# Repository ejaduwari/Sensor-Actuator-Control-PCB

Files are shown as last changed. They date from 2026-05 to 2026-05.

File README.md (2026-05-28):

# Sensor-Actuator-Control-PCB
STM32F103C8 carrier board controlling 6 stepper motors, servos, limit switches, and IO expanders with UART, SPI, and I2C interfaces. Includes full pin mapping, dual-regulator power design, and detailed failure analysis with debugging insights and hardware lessons learned.



# 📘 STM32F103C8 Stepper Motor Controller  
### Carrier Board + Small Pill Architecture & Debug Report

---

## 📑 Table of Contents
- [Overview](#overview)
- [Hardware Architecture](#hardware-architecture)
- [Pin Mapping (STM32 ↔ Carrier Board)](#pin-mapping-stm32--carrier-board)
- [Peripheral Interfaces](#peripheral-interfaces)
- [Clock & Crystal](#clock--crystal)
- [Power System Design](#power-system-design)
- [IO Expanders](#io-expanders)
- [Failure Report & Debugging](#failure-report--debugging)
- [Root Cause Analysis](#root-cause-analysis)
- [Current Status](#current-status)
- [Design Lessons & Prevention](#design-lessons--prevention)

---

## 🔍 Overview

This project is a **custom STM32F103C8-based PCB** designed to control:
- Multiple **A4988 stepper drivers**
- Several **servo outputs**
- External IO via expanders

The board uses a **Small Pill (STM32F103C8T6)** mounted on a **carrier board**, providing structured routing for motion control and expansion.

---

## 🧩 Hardware Architecture

- **MCU:** STM32F103C8T6 (Small Pill)
- **Motor Drivers:** A4988 (external)
- **IO Expansion:** PI4IOE5V6416
- **Power Inputs:**
  - USB (via L78L00 regulator)
  - External 5V (via AP2112K-3.3)
- **Control Signals:**
  - STEP / DIR for 6 axes
  - Servo PWM outputs
- **Debug Interface:**
  - SWD (SWCLK, SWDIO)

---

## 🔌 Pin Mapping (STM32 ↔ Carrier Board)

| STM32 Pin | Function |
|---|---|
| PA0 | 5_DIR |
| PA1 | 5_STP |
| PA2 | TX |
| PA3 | RX |
| PA4 | 1_DIR |
| PA5 | SCK |
| PA6 | MISO |
| PA7 | MOSI |
| PA8 | SERVO_1_3V3 |
| PA9 | SERVO_2_3V3 |
| PA10 | SERVO_3_3V3 |
| PA11 | USB- |
| PA12 | USB+ |
| PA15 | SERVO_4_3V3 |

| STM32 Pin | Function |
|---|---|
| PB0 | 4_STP |
| PB1 | 4_DIR |
| PB2 | BOOT |
| PB3 | 3_STP |
| PB4 | SERVO_6_3V3 |
| PB5 | SW9 |
| PB6 | SCL |
| PB7 | SDA |
| PB8 | 6_DIR |
| PB9 | SW10 |
| PB10 | 3_DIR |
| PB11 | 6_STP |
| PB12 | LED |
| PB13 | GPIO |
| PB14 | GPIO |
| PB15 | GPIO |

| STM32 Pin | Function |
|---|---|
| PC13 | 2_DIR |
| PC14 | 2_STP |
| PC15 | 1_STP |

| Debug Pins | Function |
|---|---|
| PA13 | SWDIO |
| PA14 | SWCLK |
| NRST | Reset |

---

## 🔗 Peripheral Interfaces

### UART
- TX: PA2  
- RX: PA3  

### SPI
- SCK: PA5  
- MISO: PA6  
- MOSI: PA7  

### I2C
- SCL: PB6  
- SDA: PB7  

---

## ⏱ Clock & Crystal

- **Component:** 25 MHz SMD Crystal  
- **Capacitance:** 20pF  
- **Package:** 3.2mm × 2.5mm  

- **DigiKey Part #:** 3155-25M20P2/XT324-10/10CT-ND  
- **Manufacturer #:** 25M20P2/XT324-10/10  

---

## ⚡ Power System Design

### Regulators

**1. L78L00**
- Input: USB (~5V)
- Output: 3.3V (intended)
- Status: ❌ Damaged / unstable

**2. AP2112K-3.3**
- Input: External 5V
- Output: 3.3V
- Status: ✅ Functional

---

### Observed Behavior

- With motors connected:
  - 3.3V rail dropped to ~3.0V
- With L78L00 removed:
  - Stable 3.29V from AP2112K
- Backfeeding observed across regulators

---

## 🔌 IO Expanders

- **Model:** PI4IOE5V6416  
- Used for:
  - Microstepping control
  - Enable signals

⚠️ These lines interface with high-current drivers → risk area

---

## 🧪 Failure Report & Debugging

### Initial Symptoms

- PB12 LED stopped working
- MCU still flashable (initially)
- Reset did not recover functionality

---

### Voltage Measurements

| Condition | Observation |
|---|---|
| Motors connected | 3.3V ~3.0V |
| PB12 | ~0.12V |
| After disconnecting 12V | PB12 still ~0.12V |
| Reset held | 3.3V rises slightly |

---

### GPIO Testing

- PB12–PB15 stuck at ~0.12V
- PB15 toggle test failed
- Same issue after MCU replacement

---

### Regulator Testing

- L78L00:
  - Input ~4.8V
  - Output unstable / low
- AP2112K:
  - Output stable at ~3.29V

---

### Fuse

- 0685H9100-01 → OK (~0Ω)

---

### After L78L00 Removal

- System powered via AP2112K
- 3.3V stable
- ❌ Flashing failed:
  - Error in final launch sequence
  - Failed to start GDB server

---

## 🔎 Root Cause Analysis

### 1. GPIO Damage
- PB12–PB15 permanently stuck low
- Cause: **Backfeed / overvoltage from stepper drivers**
- Likely triggered by:
- Swapping motor wires while powered

---

### 2. Power Rail Instability
- L78L00 regulator damaged
- Caused rail drops under load

---

### 3. Regulator Conflict
- Backfeeding between regulators
- L78L00 became ineffective

---

### 4. Flashing Failure
- Likely due to:
- Unstable VDD reference
- Improper SWD voltage levels

---

## 📉 Current Status

- ❌ Original MCU damaged (GPIO bank failure)
- ⚠️ Replacement MCU still showing abnormal GPIO behavior
- ✅ AP2112K regulator working
- ❌ Board cannot be flashed
- ❌ System non-functional

---

## 🛠 Design Lessons & Prevention

### Critical Rules

- ❌ Never swap stepper wires under power
- ❌ Avoid direct MCU exposure to driver signals

---

### Recommended Fixes

- Add **series resistors** on control lines
- Use **optocouplers or buffers**
- Isolate **high-current paths**
- Ensure **single clean 3.3V source**
- Avoid regulator backfeeding

---

### Debug Best Practices

- Verify rails before applying load
- Test MCU pins before connecting drivers
- Use current limiting during bring-up

---

## 🚧 Final Note

This failure highlights a critical embedded design principle:

> **Power integrity and signal protection are just as important as logic design.**

Future revisions should prioritize:
- Electrical isolation
- Robust power architecture
- Safer bring-up procedures

---

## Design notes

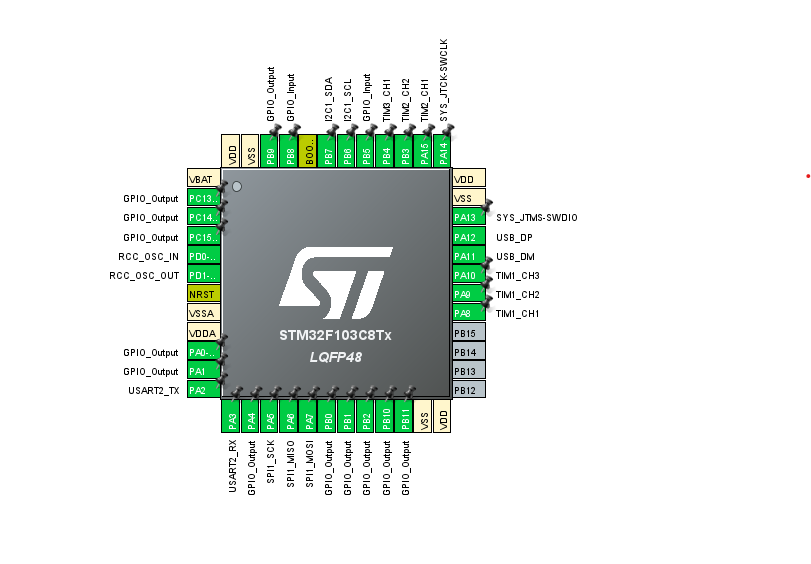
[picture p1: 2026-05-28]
pin map.png

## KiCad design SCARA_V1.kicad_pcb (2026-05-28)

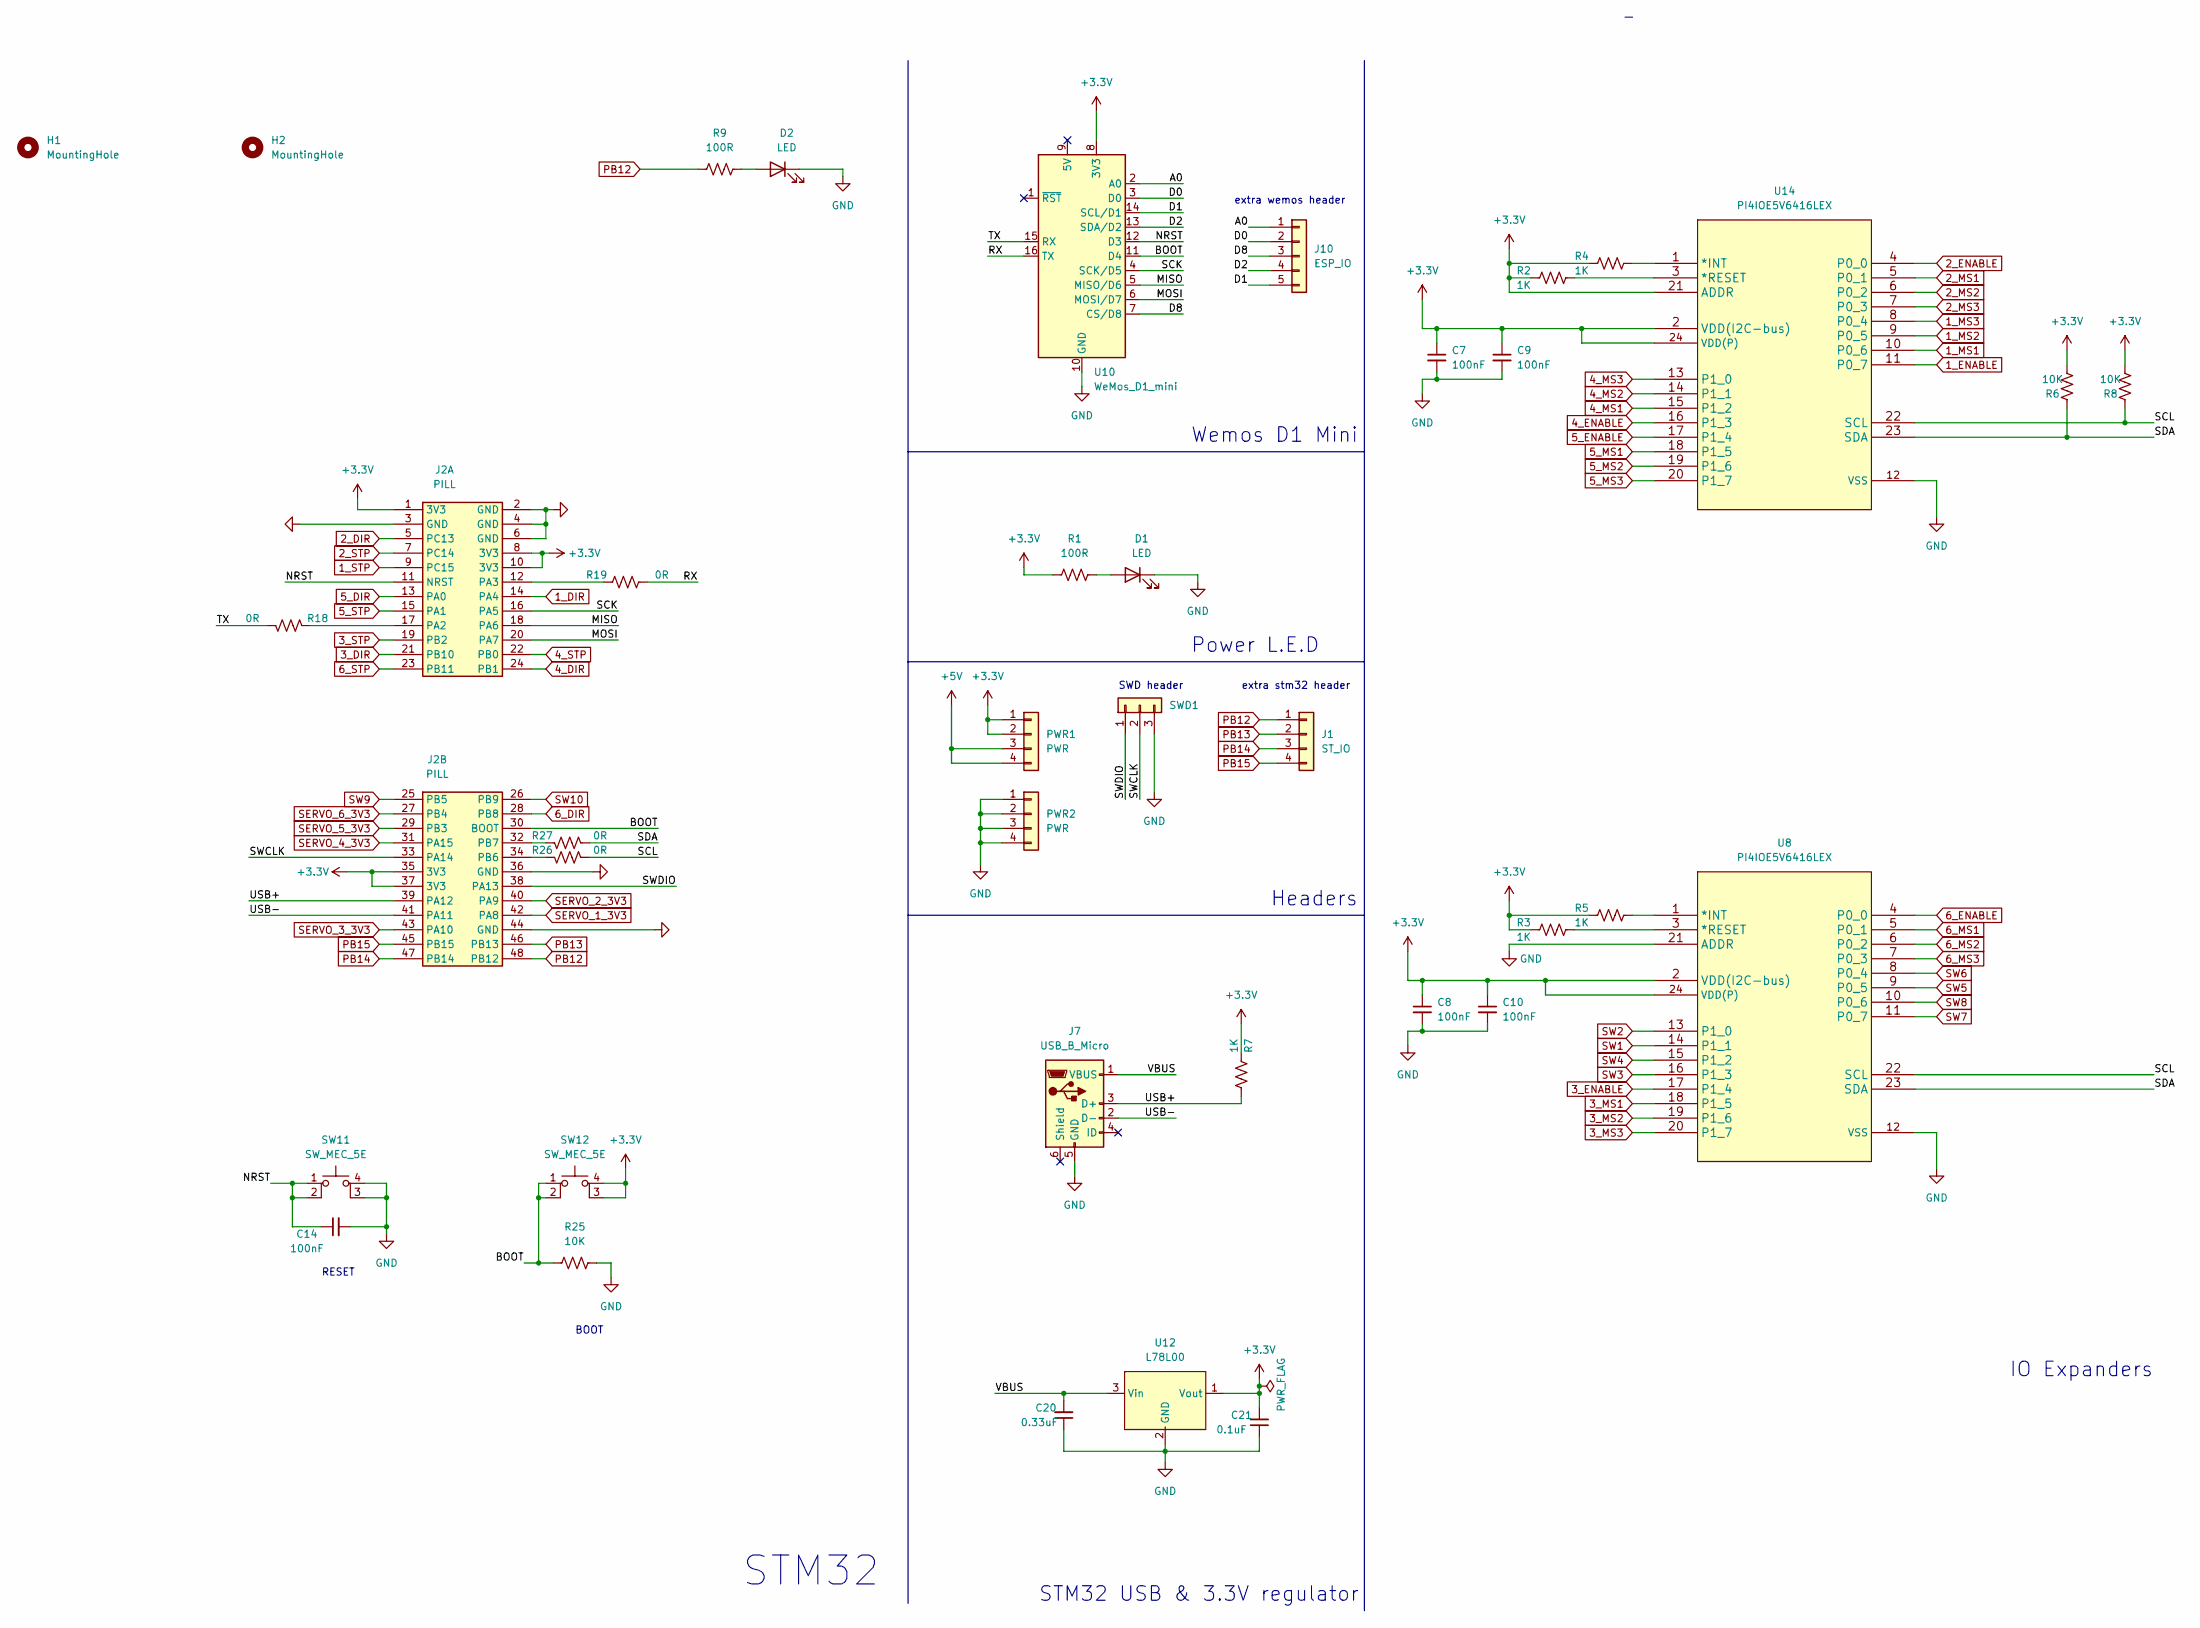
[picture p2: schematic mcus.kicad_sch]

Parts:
C7, C8, C9, C10: 100nF; C_0402_1005Metric
C14: 100nF; C_0805_2012Metric
C20: 0.33uF; C_0805_2012Metric_Pad1.18x1.45mm_HandSolder
C21: 0.1uF; C_0805_2012Metric_Pad1.18x1.45mm_HandSolder
D1, D2: LED; LED_0805_2012Metric
H1, H2: MountingHole; MountingHole_3.5mm
J1: ST_IO; PinHeader_1x04_P2.54mm_Vertical
J2: PILL
J7: USB_B_Micro; USB_Micro-B_Molex-105017-0001
J10: ESP_IO; PinHeader_1x05_P2.54mm_Vertical
PWR1, PWR2: PWR; PinHeader_1x04_P2.54mm_Vertical
R1, R9: 100R; R_0805_2012Metric
R2, R3, R4, R5, R7: 1K; R_0805_2012Metric
R6, R8, R25: 10K; R_0805_2012Metric
R18, R19, R26, R27: 0R; R_0805_2012Metric
SW11, SW12: SW_MEC_5E; PTS830GM140SMTRLFS
SWD1: Conn_01x03; PinHeader_1x03_P2.54mm_Vertical
U8, U14: PI4IOE5V6416LEX; TSSOP-24_4.4x7.8mm_P0.65mm
U10: WeMos_D1_mini; WEMOS_D1_mini_light
U12: L78L00; SOT-89-3

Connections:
1_DIR: J2.14 (PA4); also elsewhere on the board
1_ENABLE: U14.11 (P0_7); also elsewhere on the board
1_MS1: U14.10 (P0_6); also elsewhere on the board
1_MS2: U14.9 (P0_5); also elsewhere on the board
1_MS3: U14.8 (P0_4); also elsewhere on the board
1_STP: J2.9 (PC15); also elsewhere on the board
2_DIR: J2.5 (PC13); also elsewhere on the board
2_ENABLE: U14.4 (P0_0); also elsewhere on the board
2_MS1: U14.5 (P0_1); also elsewhere on the board
2_MS2: U14.6 (P0_2); also elsewhere on the board
2_MS3: U14.7 (P0_3); also elsewhere on the board
2_STP: J2.7 (PC14); also elsewhere on the board
3_DIR: J2.21 (PB10); also elsewhere on the board
3_ENABLE: U8.17 (P1_4); also elsewhere on the board
3_MS1: U8.18 (P1_5); also elsewhere on the board
3_MS2: U8.19 (P1_6); also elsewhere on the board
3_MS3: U8.20 (P1_7); also elsewhere on the board
3_STP: J2.19 (PB2); also elsewhere on the board
4_DIR: J2.24 (PB1); also elsewhere on the board
4_ENABLE: U14.16 (P1_3); also elsewhere on the board
4_MS1: U14.15 (P1_2); also elsewhere on the board
4_MS2: U14.14 (P1_1); also elsewhere on the board
4_MS3: U14.13 (P1_0); also elsewhere on the board
4_STP: J2.22 (PB0); also elsewhere on the board
5_DIR: J2.13 (PA0); also elsewhere on the board
5_ENABLE: U14.17 (P1_4); also elsewhere on the board
5_MS1: U14.18 (P1_5); also elsewhere on the board
5_MS2: U14.19 (P1_6); also elsewhere on the board
5_MS3: U14.20 (P1_7); also elsewhere on the board
5_STP: J2.15 (PA1); also elsewhere on the board
6_DIR: J2.28 (PB8); also elsewhere on the board
6_ENABLE: U8.4 (P0_0); also elsewhere on the board
6_MS1: U8.5 (P0_1); also elsewhere on the board
6_MS2: U8.6 (P0_2); also elsewhere on the board
6_MS3: U8.7 (P0_3); also elsewhere on the board
6_STP: J2.23 (PB11); also elsewhere on the board
+3.3V: C7.1, C8.1, C9.1, C10.1, C21.2, J2.1 (3V3), J2.8 (3V3), J2.10 (3V3), J2.35 (3V3), J2.37 (3V3), PWR1.1, PWR1.2, R1.1, R2.2, R3.2, R4.2, R5.2, R6.1, R7.2, R8.1, SW12.3 (K), SW12.4 (A), U8.2 (VDD(I2C-bus)), U8.24 (VDD(P)), U10.8 (3V3), U12.1 (Vout), U14.2 (VDD(I2C-bus)), U14.21 (ADDR), U14.24 (VDD(P)); also elsewhere on the board
+5V: PWR1.3, PWR1.4; also elsewhere on the board
/MCUs/A0: J10.1, U10.2 (A0)
/MCUs/BOOT: J2.30 (BOOT), R25.1, SW12.1, SW12.2, U10.11 (D4)
/MCUs/D0: J10.2, U10.3 (D0)
/MCUs/D1: J10.5, U10.14 (SCL/D1)
/MCUs/D2: J10.4, U10.13 (SDA/D2)
/MCUs/D8: J10.3, U10.7 (CS/D8)
/MCUs/MISO: J2.18 (PA6), U10.5 (MISO/D6)
/MCUs/MOSI: J2.20 (PA7), U10.6 (MOSI/D7)
/MCUs/NRST: C14.1, J2.11 (NRST), SW11.1, SW11.2, U10.12 (D3)
/MCUs/RX: R19.2, U10.16 (TX)
/MCUs/SCK: J2.16 (PA5), U10.4 (SCK/D5)
/MCUs/SCL: R8.2, R26.1, U8.22 (SCL), U14.22 (SCL)
/MCUs/SDA: R6.2, R27.1, U8.23 (SDA), U14.23 (SDA)
/MCUs/SWCLK: J2.33 (PA14), SWD1.2
/MCUs/SWDIO: J2.38 (PA13), SWD1.1
/MCUs/TX: R18.2, U10.15 (RX)
/MCUs/USB+: J2.39 (PA12), J7.3 (D+), R7.1
/MCUs/USB-: J2.41 (PA11), J7.2 (D-)
/MCUs/VBUS: C20.2, J7.1 (VBUS), U12.3 (Vin)
GND: C7.2, C8.2, C9.2, C10.2, C14.2, C20.1, C21.1, D1.1 (K), D2.1 (K), J2.2 (GND), J2.3 (GND), J2.4 (GND), J2.6 (GND), J2.36 (GND), J2.44 (GND), J7.5 (GND), PWR2.1, PWR2.2, PWR2.3, PWR2.4, R25.2, SW11.3 (K), SW11.4 (A), SWD1.3, U8.12 (VSS), U8.21 (ADDR), U10.10 (GND), U12.2 (GND), U14.12 (VSS); also elsewhere on the board
unnamed: D1.2 (A), R1.2
unnamed: D2.2 (A), R9.2
unnamed: J2.12 (PA3), R19.1
unnamed: J2.17 (PA2), R18.1
unnamed: J2.32 (PB7), R27.2
unnamed: J2.34 (PB6), R26.2
unnamed: R2.1, U14.3 (*RESET)
unnamed: R3.1, U8.3 (*RESET)
unnamed: R4.1, U14.1 (*INT)
unnamed: R5.1, U8.1 (*INT)
PB12: J1.1, J2.48 (PB12), R9.1
PB13: J1.2, J2.46 (PB13)
PB14: J1.3, J2.47 (PB14)
PB15: J1.4, J2.45 (PB15)
SERVO_1_3V3: J2.42 (PA8); also elsewhere on the board
SERVO_2_3V3: J2.40 (PA9); also elsewhere on the board
SERVO_3_3V3: J2.43 (PA10); also elsewhere on the board
SERVO_4_3V3: J2.31 (PA15); also elsewhere on the board
SERVO_5_3V3: J2.29 (PB3); also elsewhere on the board
SERVO_6_3V3: J2.27 (PB4); also elsewhere on the board
SW1: U8.14 (P1_1); also elsewhere on the board
SW2: U8.13 (P1_0); also elsewhere on the board
SW3: U8.16 (P1_3); also elsewhere on the board
SW4: U8.15 (P1_2); also elsewhere on the board
SW5: U8.9 (P0_5); also elsewhere on the board
SW6: U8.8 (P0_4); also elsewhere on the board
SW7: U8.11 (P0_7); also elsewhere on the board
SW8: U8.10 (P0_6); also elsewhere on the board
SW9: J2.25 (PB5); also elsewhere on the board
SW10: J2.26 (PB9); also elsewhere on the board

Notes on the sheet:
extra stm32 header
STM32
extra wemos header
SWD header
IO Expanders
Wemos D1 Mini
BOOT
STM32 USB & 3.3V regulator
RESET
Power L.E.D
Headers

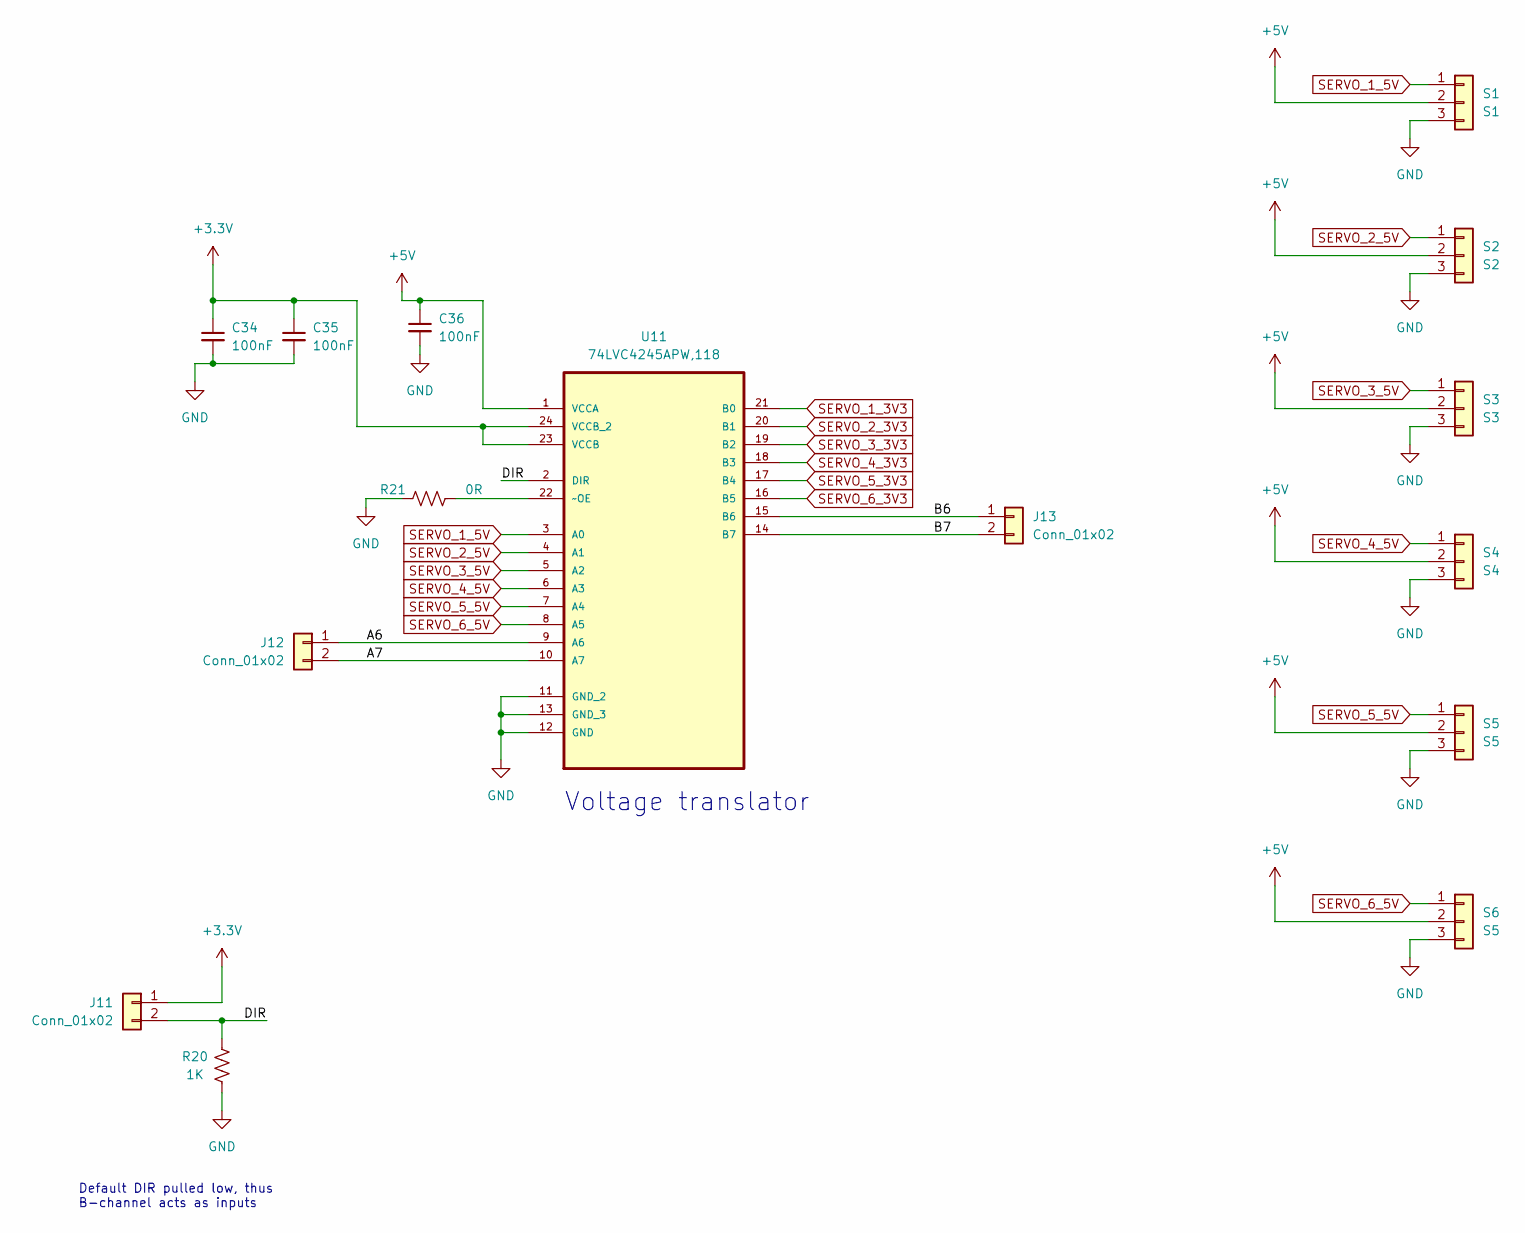
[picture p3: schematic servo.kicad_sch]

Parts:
C34, C35, C36: 100nF; C_0805_2012Metric
J11, J12, J13: Conn_01x02; PinHeader_1x02_P2.54mm_Vertical
R20: 1K; R_0805_2012Metric
R21: 0R; R_0805_2012Metric
S1: S1; PinHeader_1x03_P2.54mm_Vertical
S2: S2; PinHeader_1x03_P2.54mm_Vertical
S3: S3; PinHeader_1x03_P2.54mm_Vertical
S4: S4; PinHeader_1x03_P2.54mm_Vertical
S5, S6: S5; PinHeader_1x03_P2.54mm_Vertical
U11: 74LVC4245APW,118; SOP65P640X110-24N; MPN 74LVC4245APW,118

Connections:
+3.3V: C34.1, C35.1, J11.1, U11.23 (VCCB), U11.24 (VCCB_2); also elsewhere on the board
+5V: C36.1, S1.2, S2.2, S3.2, S4.2, S5.2, S6.2, U11.1 (VCCA); also elsewhere on the board
/SERVOS/A6: J12.1, U11.9 (A6)
/SERVOS/A7: J12.2, U11.10 (A7)
/SERVOS/B6: J13.1, U11.15 (B6)
/SERVOS/B7: J13.2, U11.14 (B7)
/SERVOS/DIR: J11.2, R20.2, U11.2 (DIR)
GND: C34.2, C35.2, C36.2, R20.1, R21.1, S1.3, S2.3, S3.3, S4.3, S5.3, S6.3, U11.11 (GND_2), U11.12 (GND), U11.13 (GND_3); also elsewhere on the board
unnamed: R21.2, U11.22 (~OE)
SERVO_1_3V3: U11.21 (B0); also elsewhere on the board
SERVO_1_5V: S1.1, U11.3 (A0)
SERVO_2_3V3: U11.20 (B1); also elsewhere on the board
SERVO_2_5V: S2.1, U11.4 (A1)
SERVO_3_3V3: U11.19 (B2); also elsewhere on the board
SERVO_3_5V: S3.1, U11.5 (A2)
SERVO_4_3V3: U11.18 (B3); also elsewhere on the board
SERVO_4_5V: S4.1, U11.6 (A3)
SERVO_5_3V3: U11.17 (B4); also elsewhere on the board
SERVO_5_5V: S5.1, U11.7 (A4)
SERVO_6_3V3: U11.16 (B5); also elsewhere on the board
SERVO_6_5V: S6.1, U11.8 (A5)

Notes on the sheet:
Default DIR pulled low, thus B-channel acts as inputs
Voltage translator

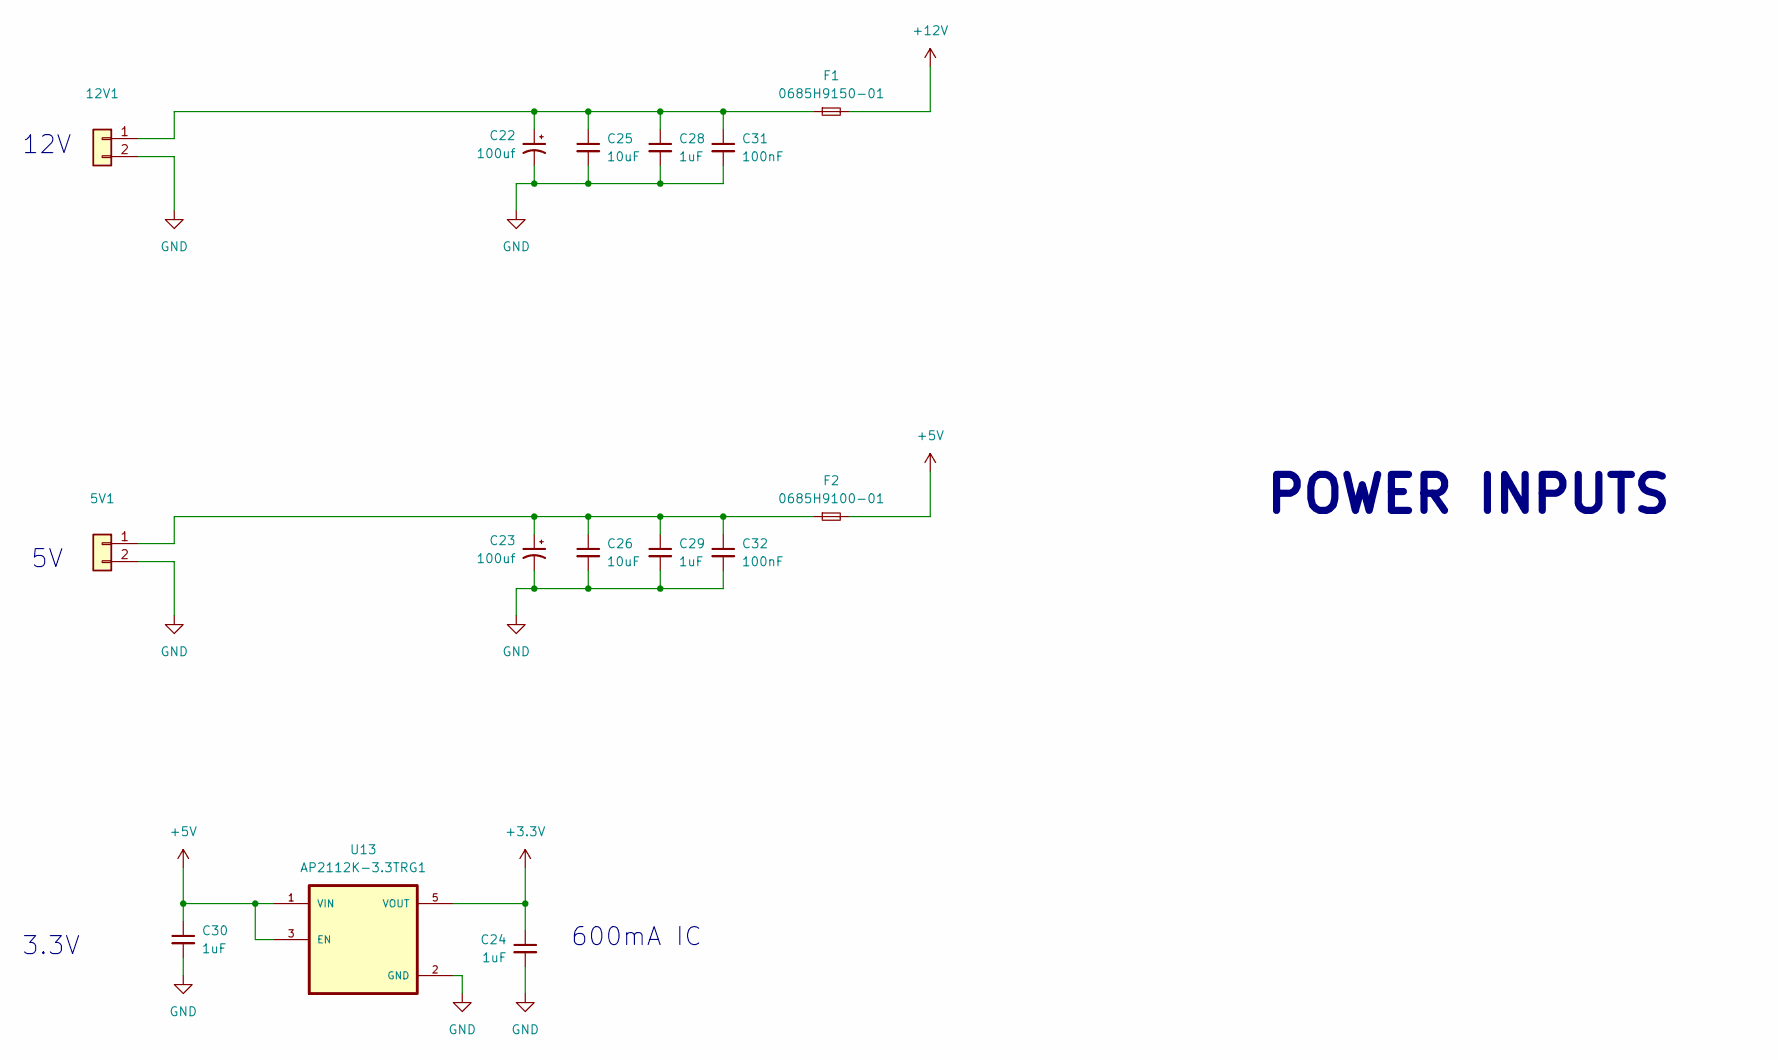
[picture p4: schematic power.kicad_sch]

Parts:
5V1, 12V1: Conn_01x02; PinHeader_1x02_P2.54mm_Vertical
C22, C23: 100uf; CP_Radial_D6.3mm_P2.50mm
C24, C28, C29, C30: 1uF; C_0805_2012Metric
C25, C26: 10uF; C_0805_2012Metric
C31, C32: 100nF; C_0805_2012Metric
F1: 0685H9150-01; 3.2x1.58
F2: 0685H9100-01; 3.2x1.58
U13: AP2112K-3.3TRG1; SOT95P285X140-5N; PARTREV 2-2

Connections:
+3.3V: C24.1, U13.5 (VOUT); also elsewhere on the board
+5V: C30.1, F2.2, U13.1 (VIN), U13.3 (EN); also elsewhere on the board
+12V: F1.2; also elsewhere on the board
GND: 5V1.2, 12V1.2, C22.2, C23.2, C24.2, C25.2, C26.2, C28.2, C29.2, C30.2, C31.2, C32.2, U13.2 (GND); also elsewhere on the board
unnamed: 5V1.1, C23.1, C26.1, C29.1, C32.1, F2.1
unnamed: 12V1.1, C22.1, C25.1, C28.1, C31.1, F1.1

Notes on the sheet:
600mA IC
12V
POWER INPUTS
3.3V

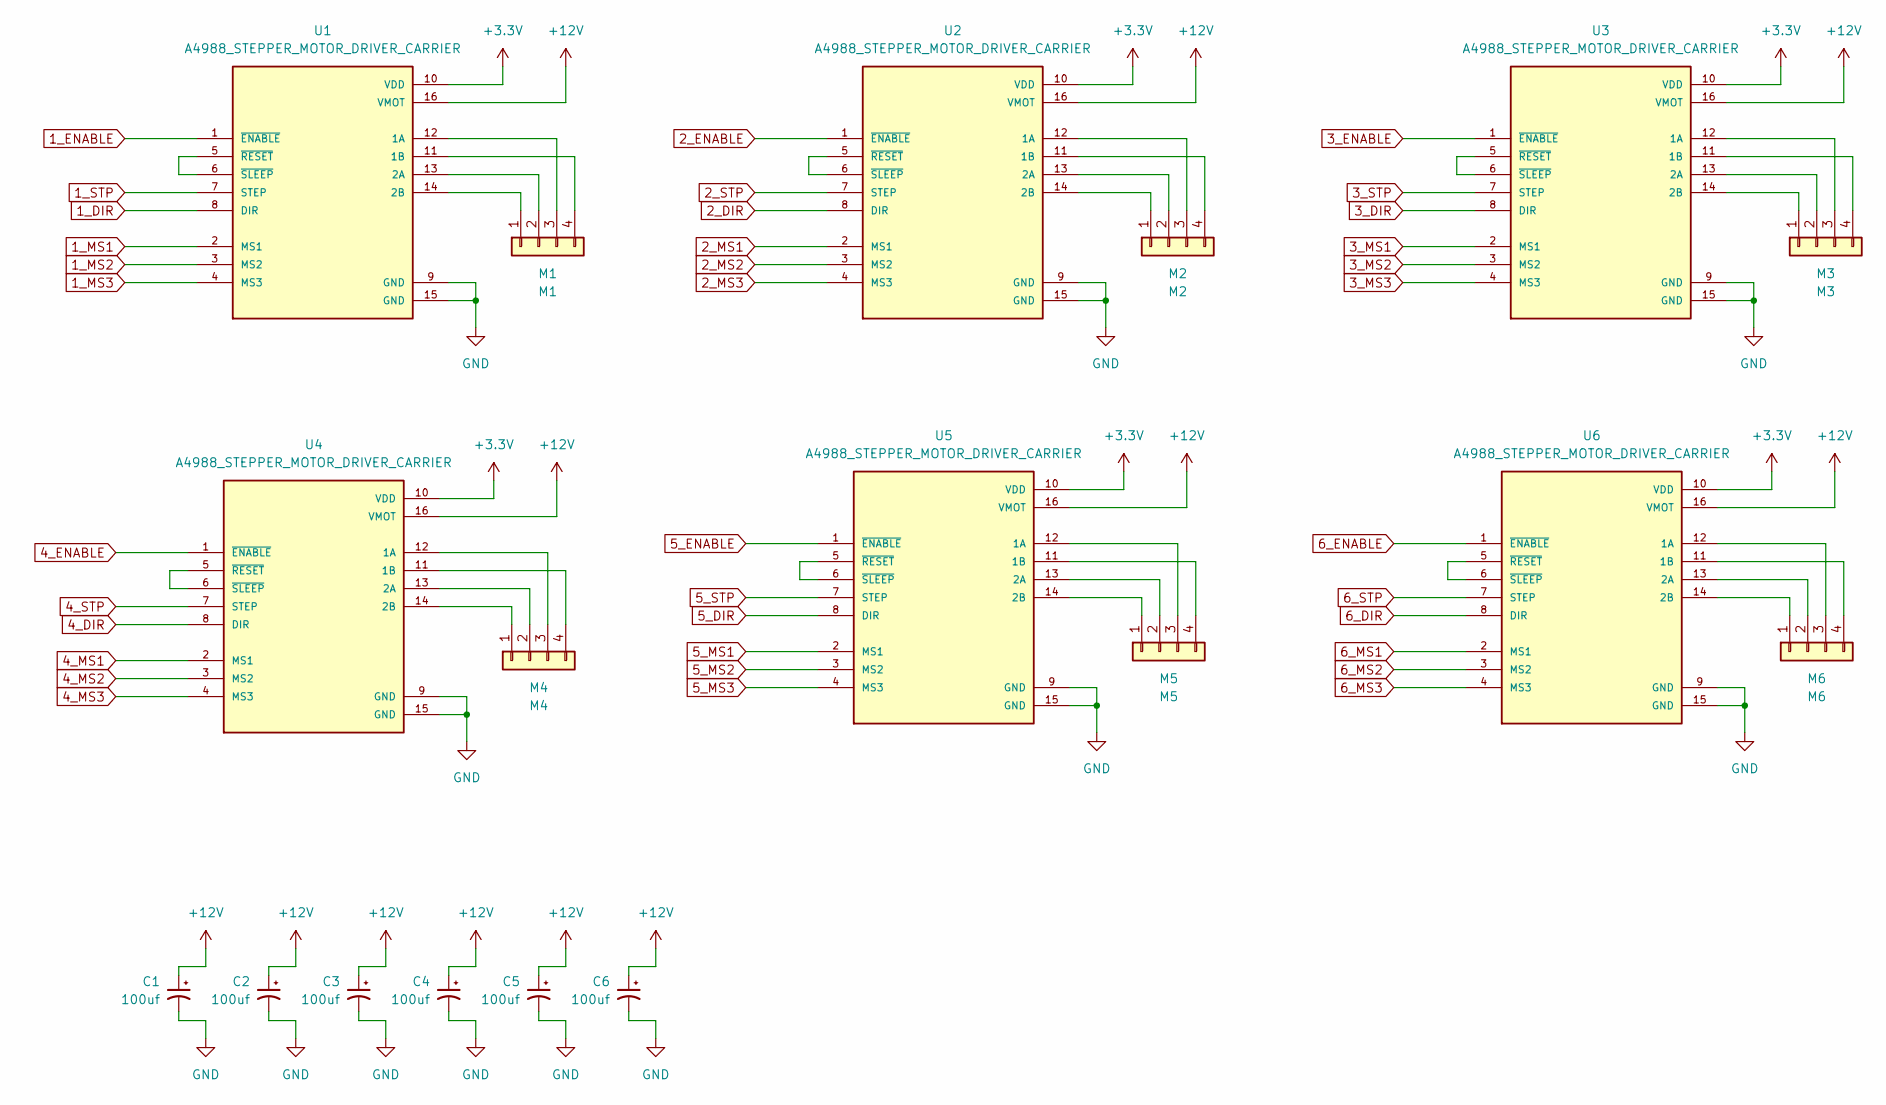
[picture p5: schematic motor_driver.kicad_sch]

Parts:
C1, C2, C3, C4, C5, C6: 100uf; CP_Radial_D6.3mm_P2.50mm
M1: M1; PinHeader_1x04_P2.54mm_Vertical
M2: M2; PinHeader_1x04_P2.54mm_Vertical
M3: M3; PinHeader_1x04_P2.54mm_Vertical
M4: M4; PinHeader_1x04_P2.54mm_Vertical
M5: M5; PinHeader_1x04_P2.54mm_Vertical
M6: M6; PinHeader_1x04_P2.54mm_Vertical
U1, U2, U3, U4, U5, U6: A4988_STEPPER_MOTOR_DRIVER_CARRIER; MODULE_A4988_STEPPER_MOTOR_DRIVER_CARRIER

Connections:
1_DIR: U1.8 (DIR); also elsewhere on the board
1_ENABLE: U1.1 (~ENABLE); also elsewhere on the board
1_MS1: U1.2 (MS1); also elsewhere on the board
1_MS2: U1.3 (MS2); also elsewhere on the board
1_MS3: U1.4 (MS3); also elsewhere on the board
1_STP: U1.7 (STEP); also elsewhere on the board
2_DIR: U2.8 (DIR); also elsewhere on the board
2_ENABLE: U2.1 (~ENABLE); also elsewhere on the board
2_MS1: U2.2 (MS1); also elsewhere on the board
2_MS2: U2.3 (MS2); also elsewhere on the board
2_MS3: U2.4 (MS3); also elsewhere on the board
2_STP: U2.7 (STEP); also elsewhere on the board
3_DIR: U3.8 (DIR); also elsewhere on the board
3_ENABLE: U3.1 (~ENABLE); also elsewhere on the board
3_MS1: U3.2 (MS1); also elsewhere on the board
3_MS2: U3.3 (MS2); also elsewhere on the board
3_MS3: U3.4 (MS3); also elsewhere on the board
3_STP: U3.7 (STEP); also elsewhere on the board
4_DIR: U4.8 (DIR); also elsewhere on the board
4_ENABLE: U4.1 (~ENABLE); also elsewhere on the board
4_MS1: U4.2 (MS1); also elsewhere on the board
4_MS2: U4.3 (MS2); also elsewhere on the board
4_MS3: U4.4 (MS3); also elsewhere on the board
4_STP: U4.7 (STEP); also elsewhere on the board
5_DIR: U5.8 (DIR); also elsewhere on the board
5_ENABLE: U5.1 (~ENABLE); also elsewhere on the board
5_MS1: U5.2 (MS1); also elsewhere on the board
5_MS2: U5.3 (MS2); also elsewhere on the board
5_MS3: U5.4 (MS3); also elsewhere on the board
5_STP: U5.7 (STEP); also elsewhere on the board
6_DIR: U6.8 (DIR); also elsewhere on the board
6_ENABLE: U6.1 (~ENABLE); also elsewhere on the board
6_MS1: U6.2 (MS1); also elsewhere on the board
6_MS2: U6.3 (MS2); also elsewhere on the board
6_MS3: U6.4 (MS3); also elsewhere on the board
6_STP: U6.7 (STEP); also elsewhere on the board
+3.3V: U1.10 (VDD), U2.10 (VDD), U3.10 (VDD), U4.10 (VDD), U5.10 (VDD), U6.10 (VDD); also elsewhere on the board
+12V: C1.1, C2.1, C3.1, C4.1, C5.1, C6.1, U1.16 (VMOT), U2.16 (VMOT), U3.16 (VMOT), U4.16 (VMOT), U5.16 (VMOT), U6.16 (VMOT); also elsewhere on the board
GND: C1.2, C2.2, C3.2, C4.2, C5.2, C6.2, U1.9 (GND), U1.15 (GND), U2.9 (GND), U2.15 (GND), U3.9 (GND), U3.15 (GND), U4.9 (GND), U4.15 (GND), U5.9 (GND), U5.15 (GND), U6.9 (GND), U6.15 (GND); also elsewhere on the board
unnamed: M1.1, U1.14 (2B)
unnamed: M1.2, U1.13 (2A)
unnamed: M1.3, U1.12 (1A)
unnamed: M1.4, U1.11 (1B)
unnamed: M2.1, U2.14 (2B)
unnamed: M2.2, U2.13 (2A)
unnamed: M2.3, U2.12 (1A)
unnamed: M2.4, U2.11 (1B)
unnamed: M3.1, U3.14 (2B)
unnamed: M3.2, U3.13 (2A)
unnamed: M3.3, U3.12 (1A)
unnamed: M3.4, U3.11 (1B)
unnamed: M4.1, U4.14 (2B)
unnamed: M4.2, U4.13 (2A)
unnamed: M4.3, U4.12 (1A)
unnamed: M4.4, U4.11 (1B)
unnamed: M5.1, U5.14 (2B)
unnamed: M5.2, U5.13 (2A)
unnamed: M5.3, U5.12 (1A)
unnamed: M5.4, U5.11 (1B)
unnamed: M6.1, U6.14 (2B)
unnamed: M6.2, U6.13 (2A)
unnamed: M6.3, U6.12 (1A)
unnamed: M6.4, U6.11 (1B)
unnamed: U1.5 (~RESET), U1.6 (~SLEEP)
unnamed: U2.5 (~RESET), U2.6 (~SLEEP)
unnamed: U3.5 (~RESET), U3.6 (~SLEEP)
unnamed: U4.5 (~RESET), U4.6 (~SLEEP)
unnamed: U5.5 (~RESET), U5.6 (~SLEEP)
unnamed: U6.5 (~RESET), U6.6 (~SLEEP)

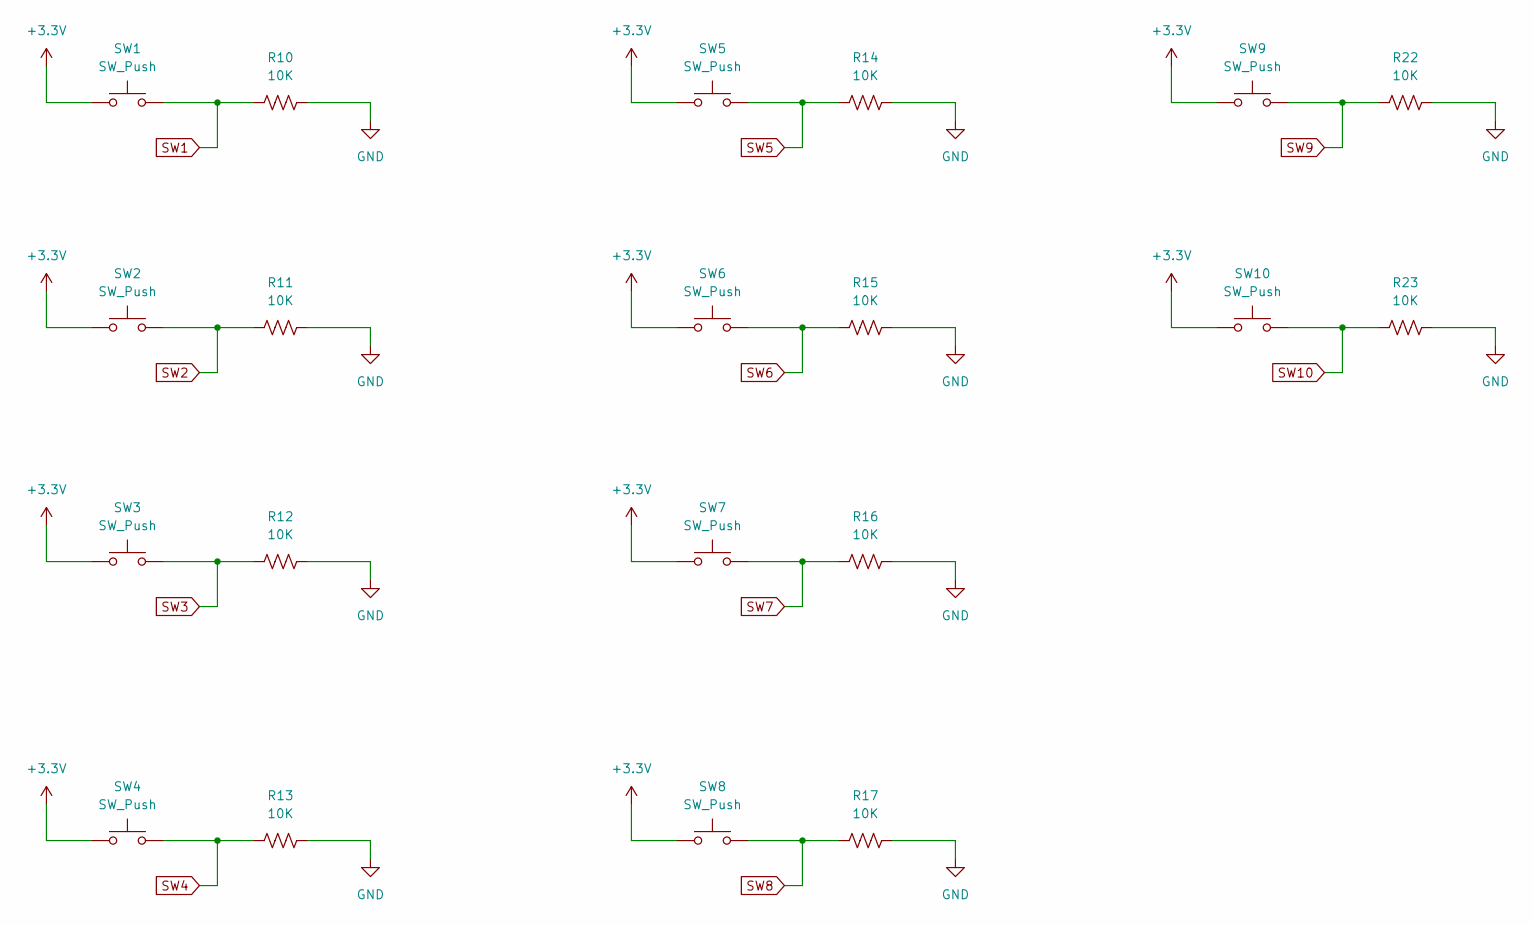
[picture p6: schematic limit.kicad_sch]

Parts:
R10, R11, R12, R13, R14, R15, R16, R17, R22, R23: 10K; R_0805_2012Metric
SW1, SW2, SW3, SW4, SW5, SW6, SW7, SW8, SW9, SW10: SW_Push; PinHeader_1x02_P2.54mm_Vertical

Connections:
+3.3V: SW1.1, SW2.1, SW3.1, SW4.1, SW5.1, SW6.1, SW7.1, SW8.1, SW9.1, SW10.1; also elsewhere on the board
GND: R10.2, R11.2, R12.2, R13.2, R14.2, R15.2, R16.2, R17.2, R22.2, R23.2; also elsewhere on the board
SW1: R10.1, SW1.2; also elsewhere on the board
SW2: R11.1, SW2.2; also elsewhere on the board
SW3: R12.1, SW3.2; also elsewhere on the board
SW4: R13.1, SW4.2; also elsewhere on the board
SW5: R14.1, SW5.2; also elsewhere on the board
SW6: R15.1, SW6.2; also elsewhere on the board
SW7: R16.1, SW7.2; also elsewhere on the board
SW8: R17.1, SW8.2; also elsewhere on the board
SW9: R22.1, SW9.2; also elsewhere on the board
SW10: R23.1, SW10.2; also elsewhere on the board

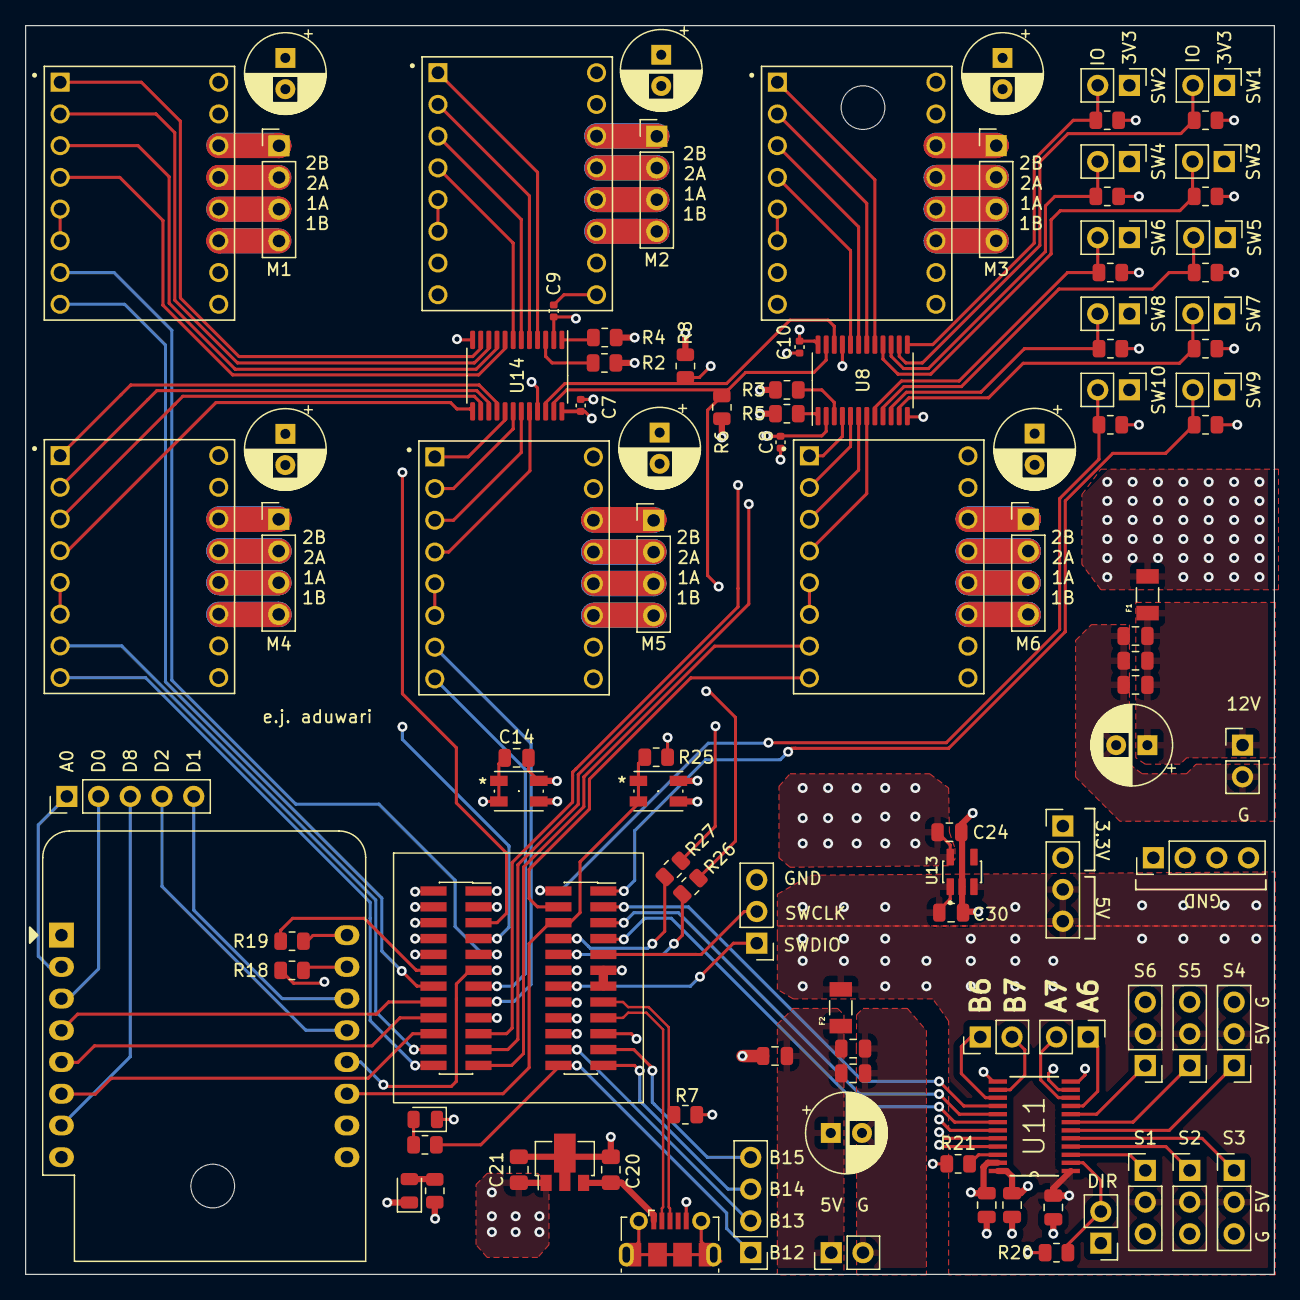
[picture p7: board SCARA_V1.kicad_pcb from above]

Board: 4 copper layers, 100.0 x 100.0 mm, 106 parts (0 on the bottom side), 133 nets.
